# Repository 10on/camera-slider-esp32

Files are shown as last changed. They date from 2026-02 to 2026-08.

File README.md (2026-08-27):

# Camera Slider (ESP32 + TMC2209 + BLE)

Надёжный контроллер моторизованного слайдера на ESP32 с реальным‑временем генерацией шагов, калибровкой, UI на OLED, энкодером, BLE‑управлением и безопасной парковкой по данным ADXL345.

## Возможности
- Реальный таймер ESP32 генерирует STEP (ровные шаги, без влияния UI/BLE)
- Режимы: ручное движение, движение к позиции, хоминг, парковка, сон, ошибка
- Хоминг с определением полного хода и центра, сохранение в NVS
- Три режима реакции на концевики: STOP, BOUNCE, PARK
- BLE‑сервис: команды, установка скорости/позиции/тока, статус (notify)
- OLED 128x64: главный экран, меню, редакторы значений, индикация ошибок
- Энкодер: навигация по меню, быстрые правки параметров
- ADXL345: детект самопроизвольного движения и безопасная парковка
- Режим сна: выключение экрана и драйвера, пробуждение по энкодеру/BLE/движению

## Аппаратная схема (кратко)
- МК: ESP32
- Драйвер: TMC2209 (UART), R_SENSE 0.11Ω, микрошаги по умолчанию 1/32, StealthChop
- I2C (SDA=8, SCL=9): PCF8574 (0x20/0x21), SSD1306 OLED (0x3C), ADXL345 (0x53/0x1D)
- Концевики и энкодер — через PCF8574; есть fallback на GPIO
- Светодиод от PCF8574, паттерны зависят от состояния

Точное назначение пинов и адреса — см. `docs/01_hardware.md`.

## Директории и файлы
- `slider.ino` — точка входа, глобальное состояние, главный цикл
- `slider_01_config.ino` — конфиг, NVS load/save, калибровка
- `slider_02_hw.ino` — инициализация TMC2209, I2C, PCF8574, OLED, ADXL345
- `slider_03_motor.ino` — ISR таймера, STEP, линейный разгон/торможение
- `slider_04_state.ino` — машина состояний, приоритеты, обработка ошибок
- `slider_05_endstops.ino` — опрос PCF8574, концевики, энкодер
- `slider_06_homing.ino` — неблокирующий хоминг по фазам
- `slider_07_adxl.ino` — детект движения и парковка
- `slider_08_ble.ino` — BLE‑сервис, колбэки, статус notify
- `slider_09_led.ino` — индикация LED через PCF8574
- `slider_10_display.ino` — отрисовка экрана и экранов меню
- `slider_11_menu.ino` — обработка энкодера, навигация, редакторы
- `slider_12_sleep.ino` — сон/пробуждение
- `docs/` — схемы, протокол BLE, спецификации UI/системы
- `old/` — предыдущие прототипы, в т.ч. `old/main_old.ino`

## Сборка и прошивка
- Платформа: Arduino IDE (ESP32 Arduino core) или PlatformIO
- Плата: ESP32 Dev Module (или соответствующий модуль ESP32)
- Откройте `slider.ino`, убедитесь, что все `.ino` файлы в одной папке проекта
- Библиотеки:
  - TMCStepper
  - Adafruit GFX Library
  - Adafruit SSD1306
  - ESP32 BLE Arduino (BLEDevice)
  - PCF8574
  - Preferences (в составе ESP32 core)
- Подключение UART к TMC2209: используется `HardwareSerial(1)` (TX=4, RX=5), 115200 бод

## Первичный запуск
1. Соберите аппаратно согласно `docs/01_hardware.md`
2. Залейте прошивку и подайте питание
3. Выполните хоминг (меню или BLE команда `H`) — сохранится ход и центр
4. Проверьте реакции на концевики, направление, микрошаги
5. При необходимости отредактируйте параметры в меню: скорость, ток, микрошаги, режим концевиков, таймаут сна, чувствительность ADXL

## Управление с устройства (OLED + энкодер)
- Главный экран: состояние, позиция (в % при калибровке или шаги), скорость, концевики, BLE
- Кнопка энкодера — вход в меню
- Меню: Manual Move, Go to Position, Calibration, Settings
- Редакторы значений: поворот — изменение, нажать — сохранить, долгий — отмена
- Хоминг: неблокирующий, прогресс и статусы фаз на экране

Подробности UI/меню: `docs/05_ui_menu(1).md`.

## BLE протокол
- Основной API: готовые программы слайдера (`Ping-Pong` по умолчанию), их параметры и
  `START/STOP` — [формат и рекомендации для пульта](docs/11_program_api.md)
- Имя устройства: Camera_Slider
- Сервис: `4fafc201-1fb5-459e-8fcc-c5c9c331914b`
- Характеристики:
  - Command (WRITE) `beb5483e-36e1-4688-b7f5-ea07361b26a8`
    - 1 байт: `F` — вперёд, `B` — назад, `S` — стоп, `H` — хоминг, `R` — сброс ошибки
  - Speed (WRITE) `d8de624e-140f-4a22-8594-e2216b84a5f2`
    - 2 байта, uint16 LE — мкс/шаг (100..5000)
  - Position (WRITE) `a1b2c3d4-e5f6-4789-a012-3456789abcde`
    - 4 байта, int32 LE — целевая позиция в шагах (требуется калибровка)
  - Current (WRITE) `f1e2d3c4-b5a6-4978-9012-3456789abcde`
    - 2 байта, uint16 LE — ток мотора в мА (200..1500)
  - Status (READ/NOTIFY) `1c95d5e3-d8f7-413a-bf3d-7a2e5d7be87e`
    - 11 байт (v2):
      - [0..3] `currentPosition` int32 LE
      - [4] флаги: бит0 E1, бит1 E2, бит2 HOMING, бит3 CAL, бит4 GO_TO, бит5 MOVING, бит6 PARK
      - [5..8] `travelDistance` int32 LE
      - [9] `state` (enum)
      - [10] `errorCode`

`F/B`, Position, Current и legacy Speed относятся к Advanced API. Движение в сторону уже
нажатого концевика блокируется прошивкой независимо от источника команды.

Подробности Advanced API и старого формата: `docs/03_ble_protocol.md`.

## Поведение и безопасность
- Реальный‑временной контур шагов — только аппаратный таймер; UI/BLE не мешают шагам
- При потерe BLE во время движения — остановка и `STATE_ERROR`
- ADXL345: в IDLE/SLEEP детектирует самодвижение и запускает парковку к ближайшему концевику
- Режимы концевиков (глобальная настройка): STOP, BOUNCE, PARK
- Сон: по таймауту в IDLE — выключение OLED и драйвера, пробуждение по энкодеру/BLE/движению

Детали архитектуры: `docs/04_system(2).md`.

## Настройки (NVS)
Сохраняются ключевые параметры: скорость, ток, микрошаги, ramp, режим концевиков, таймаут сна, чувствительность ADXL, калибровка (ход/центр). Реализация — `slider_01_config.ino`.

## Полезные советы
- Изменение микрошагов сбрасывает калибровку — требуется новый хоминг
- Для PCF8574 используйте полноценную запись байта (`write8`), чтобы не сбрасывать pull‑up на входах
- Ток подбирайте с запасом, но без перегрева двигателя/драйвера

## FAQ / открытые вопросы
Некоторые решения зафиксированы в `docs/06_questions.md` (ramp по умолчанию, скорость хоминга, формат Status v2 и др.).

## Лицензия
Не указана. Если нужно — добавьте файл LICENSE и обновите раздел.

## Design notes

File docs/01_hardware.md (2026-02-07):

# Схема подключения

## ESP32 GPIO

| GPIO | Назначение | Направление |
|---|---|---|
| 0 | EN (TMC2209) | OUTPUT |
| 1 | STEP | OUTPUT |
| 2 | DIR | OUTPUT |
| 4 | UART TX (TMC2209)| OUTPUT |
| 5 | UART RX (TMC2209)| INPUT |
| 8 | I2C SDA | — |
| 9 | I2C SCL | — |

UART для TMC2209 — HardwareSerial(1), 115200 бод.

## I2C шина (SDA=8, SCL=9)

| Адрес | Устройство | Примечание |
|---|---|---|
| 0x20  | PCF8574 | Может быть 0x21, проверяем оба |
| 0x3C  | SSD1306 OLED | 128x64 |
| 0x53  | ADXL345 | Может быть 0x1D (если SDO=HIGH) |

## PCF8574 — распиновка

| Пин | Назначение | Режим  | Примечание |
|-----|---|---|---|
| P1  | LED | OUTPUT | Индикация |
| P2  | ENC_CLK | INPUT  | Энкодер — CLK |
| P3  | ENC_DT | INPUT  | Энкодер — DT |
| P4  | ENC_SW | INPUT  | Энкодер — кнопка |
| P5  | ENDSTOP_1  | INPUT  | Концевик 1, active LOW |
| P6  | ENDSTOP_2  | INPUT  | Концевик 2, active LOW |

P0 — не работает (физический пин вырван на плате экспандера). P7 — не используется.

Важно: PCF8574 при write() делает read-modify-write всего порта.
Если входные пины притянуты к земле, write() одного пина может сбросить pull-up на остальных.
Для записи использовать `write8()` с полным байтом, где все входы = HIGH.

## TMC2209

- R_SENSE: 0.11 Ом
- Адрес драйвера: 0b00
- Микрошаги: 32
- Режим: StealthChop (spreadCycle выключен)
- Ток по умолчанию: 800 мА (диапазон 200–1500 мА)
- toff: 4

## ADXL345

- Full resolution, +-2g (3.9 mg/LSB)
- Частота: 100 Hz
- DEVID: 0xE5 (для проверки)

Ориентация на слайдере:
- **Z** — ось движения слайдера
- **X** — вверх
- **Y** — в сторону камеры (направление съёмки)

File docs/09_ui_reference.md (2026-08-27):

# UI reference — screens, menu structure, controls

Living description of what the slider's display actually shows, kept in sync with
`firmware/src/display.cpp` (drawing) and `firmware/src/menu.cpp` (navigation). The
screenshots in `docs/ui/` are generated from the same geometry, palette, glyph bitmaps and
status-bar icons the firmware uses — they are not mockups.

> **For the designer:** every image in `docs/ui/` is a 1:1 PNG at the panel's native
> 160×128. View them scaled by an integer factor (2×/4×/8×) with nearest-neighbour
> filtering; smoothing will misrepresent how this looks on the real screen. Constraints and
> known rough edges are listed in [Notes for redesign](#notes-for-redesign).

---

## 1. The canvas

| Property | Value |
|---|---|
| Panel | ST7735, **160×128**, landscape (`setRotation(1)`) |
| Colour depth | RGB565 (16-bit) |
| Font | Adafruit GFX classic 5×7 glyph in a **6×8 cell** — no other font is loaded |
| Text sizes in use | 1 (6×8 px/char), 2 (12×16), 3 (18×24) |
| Refresh | ~10 Hz, and only when something changed |
| Composition | Full 160×128 RGB565 `GFXcanvas16` (40 KB), flushed atomically over SPI |
| Backlight | PWM, user-adjustable 10–100 % |

Because the only font is a 6 px-wide bitmap, **text width is always `chars × 6 × size`
pixels**. That gives hard limits worth designing against:

| Text size | Chars per full width (160 px) |
|---|---|
| 1 | 26 |
| 2 | 13 |
| 3 | 8 |

### Standard layout bands

Nearly every screen is built from three bands:

```
y=0    ┌──────────────────────────────┐
       │ status bar (14 px)           │  BG_PANEL + 1 px DIVIDER underneath
y=14   ├──────────────────────────────┤
       │                              │
       │ content (98 px)              │  BG_BASE
       │                              │
y=112  ├──────────────────────────────┤
       │ button hints (16 px)         │  BG_PANEL + 1 px DIVIDER on top
y=128  └──────────────────────────────┘
```

The status bar shows the terse title `SLIDER` in cyan and a battery group (right): a drawn
18×9 3-segment glyph plus a `%.1f`-formatted voltage number,
with a small amber bolt to its left when a charger is detected. List-style screens replace
the title band with the screen's own name but **keep** the battery group — every screen
shows it, including Error.

The battery glyph is drawn with primitives (`drawRect`/`fillRect`), not a bitmap: 3 segments
fill green above 66/33 %, amber below 25 %, red at 0 %. This replaced the old 5-level
`bat_0..bat_4` RGB565 bitmap set specifically to drop its "opaque black background" artifact
(see [Notes for redesign](#notes-for-redesign)).

---

## 2. Controls

Three physical inputs. **BTN1 and BTN2 sit on the left flank of the enclosure, the encoder
on the right** — which is why the hint bar groups both button hints on the left and the
encoder hint on the right, rather than spreading them left/middle/right.

| Hint bar notation | Input |
|---|---|
| `▶` / `⏸` | BTN1, short press |
| `☰` | BTN2, short press |
| `(o)` | Encoder press |

Every button hint combines the physical glyph with a terse action label (`▶ STOP`,
`☰ MENU`, and so on). `▶`/`⏸`/`☰` are hand-drawn (filled triangle, two bars, three
horizontal lines): the bitmap font has no such glyphs, so these are vector primitives, not
characters. `☰` never changes shape or meaning.
`▶`/`⏸` is the one hint icon with two states, since BTN1 doubles as the actual start/stop
toggle on Main and Ping-Pong: `▶` (play) when idle — pressing starts the move — `⏸` (pause)
while running — pressing stops it. This redraws the instant the running state flips, not
just on screen entry, so it can't go stale while sitting on the same screen.

Icon colour is normally `TEXT_SEC` (dimmed further to `TEXT_DIM` when the action is
unavailable, e.g. during homing), but a few screens tint one or both to the accent that
matches the action: Main (`▶`/`⏸` cyan, `☰` amber), Ping-Pong (`▶`/`⏸` cyan), Error (`☰` red
for "HOME").

Rotation is never shown in the hint bar — it is always "adjust the thing on screen".

General rules, unless a screen overrides them:

- **BTN1** — back one level / cancel; on Main and Ping-Pong, start/stop instead (see above).
- **BTN2** — jump to the main screen. Held for 800 ms — start homing (via a confirm dialog).
- **Encoder rotate** — change the value or move the selection; **press** — confirm/select.

One detent of the encoder equals one step. (The quadrature decoder counts four transitions
per detent and divides them down; sub-detent jitter never reaches the UI.)

---

## 3. Screen map

```
MAIN ─┬─ (o) ──────────────► GO TO POSITION ──► (back to MAIN)
      ├─ 2 ────────────────► MENU
      └─ 2 held ───────────► HOMING CONFIRM ──► CALIBRATION

MENU (full-screen carousel, one item at a time, dots show position)
 ├─ Manual Move  ─────────► MANUAL MOVE
 ├─ Position     ─────────► GO TO POSITION
 ├─ Ping Pong    ─────────► PING PONG
 ├─ Calibration  ─────────► CALIBRATION
 └─ Settings     ─────────► SETTINGS
                             ├─ Motion    ──► speed / ramp / microsteps /
                             │                endstop mode / homing speed /
                             │                pingpong start           → VALUE EDIT
                             ├─ Sleep     ──► sleep timeout / ADXL sensitivity → VALUE EDIT
                             ├─ System    ──► motor current / reset calibration /
                             │                reset error / theme / brightness /
                             │                speaker on-off            → VALUE EDIT
                             │                ├─ Diagnostics ──► DIAGNOSTICS
                             │                └─ Motor Test  ──► MOTOR TEST
                             └─ Wireless  ──► Bluetooth (On/Off)  → VALUE EDIT
                                              WiFi ──► WIFI MODE
                                                        ├─ Off
                                                        ├─ Connect ──► SCAN ──► PASSWORD ──► CONNECTING
                                                        └─ Hotspot ──► PASSWORD

ERROR      — entered automatically from any screen when a fault occurs
SLEEP      — backlight off entirely; nothing is drawn
OTA UPDATE — takes over the screen while firmware is being flashed over WiFi
```

---

## 4. Screens

### 4.1 Main

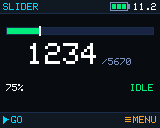
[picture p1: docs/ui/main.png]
main


The default screen. Big number is the current position in steps; the bar above it shows
where the carriage is between the two endstops (`E1` … `E2`), animated with easing.

| Input | Action |
|---|---|
| Rotate | Speed 1–100 % |
| Press | Open Go to Position |
| BTN1 (`▶`/`⏸`, cyan) | Start / stop movement in the last direction |
| BTN2 (`☰`, amber) | Open the menu |
| BTN2 held | Start homing (via confirm) |

States shown in the status line, each with its own colour: `IDLE` (green), `MOVING` /
`GO TO` (cyan), `HOMING` / `PARKING` (amber), `ERROR` (red), `SLEEP` (dim), `PING PONG`
(cyan).

| Moving | Not calibrated |
|---|---|
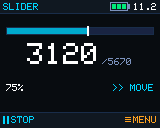
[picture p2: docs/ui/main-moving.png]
main moving
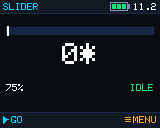
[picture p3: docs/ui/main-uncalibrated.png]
main uncalibrated
|  |  |

While moving, a direction marker (`>>` / `<<`) appears and the position bar turns cyan.
Until the slider has been homed, the position is suffixed with `*` and the bar stays empty
— travel is unknown, so there is nothing to show a fraction of.

### 4.2 Menu

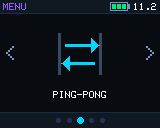
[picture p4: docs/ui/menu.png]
menu


Full-screen carousel, one item at a time: a hand-drawn vector icon (up to 60×60 px, primitives only
— no such bitmap font glyphs exist) centred in the content area, the item's name below it,
`<`/`>` chevrons at the content edges (dimmed at the first/last item — navigation itself
still wraps around, the dim chevron is just a "you're at an end" cue), and pagination dots
in the footer showing position among 5 items.

Items, in order: **Manual Move**, **Position**, **Ping Pong** (cyan icon), **Calibration**
(amber icon), **Settings** (purple icon).

| Input | Action |
|---|---|
| Rotate | Move between items |
| Press | Open the item |
| BTN1 / BTN2 | Back to main |

### 4.3 Ping Pong

No screenshot yet. Bounces the carriage between the two endstops forever, starting from a
configurable reference point (Settings → Motion → PingPong Start: Center / Endstop 1 /
Endstop 2) — this is a plain reskin of the existing bounce behavior, **not** the bounded-run
(A/B markers inside travel, dwell pause at each end, lap counter) concept sketched in the
2026-08 design handoff; that needs its own bounds-setting screen, which the handoff itself
left undesigned, and was explicitly deferred.

| Input | Action |
|---|---|
| Rotate | Speed, live |
| BTN1 (`▶`/`⏸`, cyan) | Start (heads to the reference point, then bounces) / stop |
| BTN2 | Back to the menu |

The screen uses the turn-5 hierarchy: full-width travel bar, large live position, direction
or approach state at right, and a compact speed/start/run row. Because the implemented mode
still uses the physical endstops as its bounds, its green markers sit at the two ends rather
than pretending that configurable A/B bounds exist.

### 4.4 Manual Move

| Stopped | Running |
|---|---|
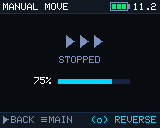
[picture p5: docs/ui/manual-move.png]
manual move
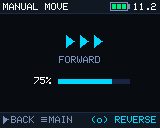
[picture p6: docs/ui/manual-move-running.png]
manual move running
|  |  |

| Input | Action |
|---|---|
| Rotate | Speed, live |
| Press | Reverse direction (reverses on the fly if already moving) |
| BTN1 | Back to the menu |
| BTN2 | Main screen |

### 4.5 Go to Position

| Calibrated | Not calibrated |
|---|---|
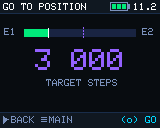
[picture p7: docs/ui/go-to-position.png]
go to position
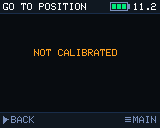
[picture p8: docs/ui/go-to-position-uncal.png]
go to position uncalibrated
|  |  |

| Input | Action |
|---|---|
| Rotate | Target position, ~1 % of total travel per detent |
| Press | Start moving to the target |
| BTN1 | Back to wherever this was opened from |
| BTN2 | Main screen |

Without calibration the slider has no coordinate system, so the screen offers nothing but
a warning.

### 4.6 Calibration / homing

| Idle | Homing in progress |
|---|---|
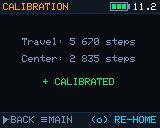
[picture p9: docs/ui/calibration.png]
calibration
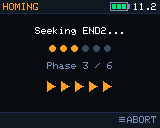
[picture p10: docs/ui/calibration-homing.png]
calibration homing
|  |  |

Homing runs in six phases (seek END1 → back off → seek END2 → back off → centre → done),
shown as a phase name and an amber progress bar. During homing every control is locked
except **BTN2 held = abort**; the measured travel and centre are stored afterwards.

### 4.7 Settings

| Settings | Motion | Sleep |
|---|---|---|
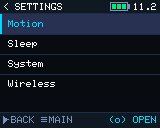
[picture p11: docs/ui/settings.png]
settings
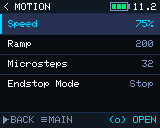
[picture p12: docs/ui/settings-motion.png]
motion
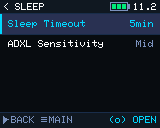
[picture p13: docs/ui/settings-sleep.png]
sleep
|  |  |  |

| System | Wireless |
|---|---|
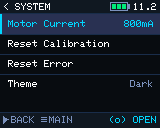
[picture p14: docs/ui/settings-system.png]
system
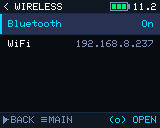
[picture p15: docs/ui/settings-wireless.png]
wireless
|  |  |

All settings screens share one list widget: 20 px rows, label left, current value right.
The selected row is a full-row highlight with a border in the selection colour and a
leading `>` marker before the label (label/value text itself stays plain white/gray, not
tinted — this replaced an earlier style that coloured the selected row's text and marked it
with a 1 px accent bar on the left edge instead). **Five rows fit at a time**; longer lists
scroll (System has eight entries as of the Speaker setting).

### 4.8 Value editor

| Numeric | Named options |
|---|---|
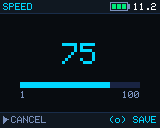
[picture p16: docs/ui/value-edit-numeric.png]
value edit numeric
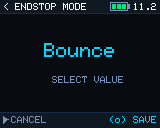
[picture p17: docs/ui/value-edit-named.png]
value edit named
|  |  |

Numeric values are centred at text size 3, with a short unit suffix (`mA`, `%`, `us`, `min`)
in `TEXT_SEC` at size 1 right after the number where the setting has an obvious one (Speed,
Homing Speed, Sleep Timeout, Motor Current, Brightness — Ramp Steps and Microsteps are
unitless). Below that, bare min/max numbers flank a progress bar directly (no "MIN"/"MAX"
caption words — one compact row instead of two). Named values (endstop mode, theme, ADXL
sensitivity, PingPong Start, Bluetooth/Speaker on-off) use size 2 and no bar — the longest
name in use, `High Contrast`, is 13 characters and only fits at that size.

| Input | Action |
|---|---|
| Rotate | Change value (microsteps step ×2 / ÷2) |
| Press | Save |
| BTN1 | Cancel |
| BTN2 | *Suppressed* — prevents discarding an edit by reflex |

### 4.9 Wireless

| WiFi mode | Scanning | Results |
|---|---|---|
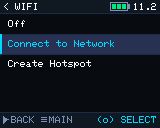
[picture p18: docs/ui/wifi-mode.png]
wifi mode
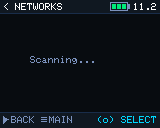
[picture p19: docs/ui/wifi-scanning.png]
scanning
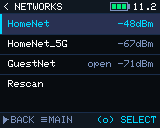
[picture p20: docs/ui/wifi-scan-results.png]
scan results
|  |  |  |

Open networks are labelled `open` next to their signal strength. The last row is always
`Rescan`.

**Password entry** — the encoder is the only text input, so characters are picked from a
74-character wheel:

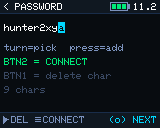
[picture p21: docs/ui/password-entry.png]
password entry


The cyan block is the cursor showing the pending character. Existing saved passwords are
pre-filled, so the common case is simply pressing BTN2.

| Input | Action |
|---|---|
| Rotate | Cycle the pending character |
| Press | Commit it and advance |
| BTN1 | Delete a character (cancels the screen when empty) |
| BTN2 | Submit (blocked for 1–7 characters: WPA2 needs at least 8) |

| Connecting | Failed |
|---|---|
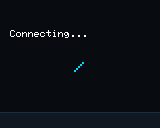
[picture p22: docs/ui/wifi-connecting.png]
connecting
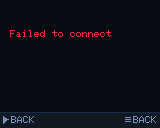
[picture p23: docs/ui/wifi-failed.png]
failed
|  |  |

Connection attempts time out after 15 s.

### 4.10 Dialogs and system screens

| Homing confirm | Error |
|---|---|
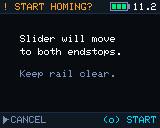
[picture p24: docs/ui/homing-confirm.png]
homing confirm
|  | error |

Homing Confirm is the one screen that asks a real yes/no question, so its footer is two
bordered "chip" buttons (`CANCEL` / `START`, amber border on the latter) instead of the
usual icon+hint row every other screen uses.

The error screen is entered automatically from any screen and its background pulses between
the base colour and dark red at 2.5 Hz. Errors: BLE connection lost, homing failed,
unexpected endstop. Footer: `▶ RESET` (dim) / `☰ HOME` (red).

**OTA update** — shown while firmware is flashed over WiFi. The main loop is fully blocked
during the transfer, so this screen is painted directly from the update callbacks:

ota update

### 4.11 Service screens

Reached from Settings → System. Both suppress all normal navigation, so nothing can be
triggered by accident while probing hardware; **hold BTN1+BTN2 for 3 s to leave**.

| Diagnostics | Motor test |
|---|---|
| diagnostics | motor test |

**Diagnostics** reads the GPIO pins directly, bypassing debouncing and the menu entirely,
so a dead switch can be told apart from a software fault. Both status LEDs mirror the
endstops here so they can be verified too.

**Motor test** jogs the motor on the bench: BTN1/BTN2 tap to run backward/forward, tapping
again (or the encoder press) stops, rotation sets speed live. Endstops are still respected.

---

## 5. Themes

Selectable in Settings → System → Theme, applied instantly and remembered.

| | Dark (default) | Light | High Contrast |
|---|---|---|---|
| Main | dark | light | hc |
| Menu | dark | light | hc |
| System | dark | light | hc |

### Palette

Colours are RGB565. Note the display cannot show more than 5/6/5 bits per channel, so
fine gradients between near neighbours will band.

| Role | Dark | Light | High Contrast |
|---|---|---|---|
| `BG_BASE` — page background | `#0A0C14` | `#F4F6FA` | `#000000` |
| `BG_PANEL` — status/hint bars | `#111827` | `#E7ECF5` | `#000000` |
| `BG_CARD` — tiles, bar troughs | `#1C2540` | `#FFFFFF` | `#000000` |
| `BG_HIGHLIGHT` — selected row/tile | `#283255` | `#D6E4FF` | `#FFFFFF` |
| `COL_SEL` — selected text/border | `#00D4FF` | `#0088B3` | `#000000` |
| `COL_CYAN` — motion / active | `#00D4FF` | `#0088B3` | `#00FFFF` |
| `COL_GREEN` — idle / success | `#00E87A` | `#128A4A` | `#00FF00` |
| `COL_AMBER` — homing / warning | `#FFA020` | `#B36B00` | `#FFEA00` |
| `COL_RED` — error / endstop hit | `#FF2840` | `#C81E3A` | `#FF0000` |
| `TEXT_PRI` — primary text | `#FFFFFF` | `#12141C` | `#FFFFFF` |
| `TEXT_SEC` — secondary text | `#7A90BB` | `#4A5670` | `#E6E6E6` |
| `TEXT_DIM` — hints, disabled | `#3A4A66` | `#8B96AC` | `#AAAAAA` |
| `DIVIDER` — 1 px rules | `#1E2E48` | `#D0D8E4` | `#666666` |

High Contrast deliberately **inverts the selection** (white block, black text) instead of
tinting it, because every accent there is already a saturated colour on black.

A 2026-08 external UI redesign handoff (mockups at real 160×128, turns 3-5) specified this
exact Dark palette independently, hex-for-hex — confirmed by converting every value back to
RGB565 and comparing. So the redesign changed screen layouts, icons, and content density,
not colour.

---

## 6. Notes for redesign

Things worth knowing before proposing changes — constraints first, then existing weak spots.

**Hard constraints**

1. **One bitmap font, three sizes.** There is no proportional font and no font scaling
   beyond integer multiples. Any type hierarchy must come from sizes 1/2/3, colour and
   spacing. Adding a font costs flash, and the build is at ~86 % of its partition.
2. **No transparency, no antialiasing.** Everything is hard-edged; overlapping elements
   must be composed by drawing order.
3. **The frame buffer is finite.** A full RGB565 `GFXcanvas16` consumes 40 KB of heap. All
   widgets compose into it, then `flushFrame()` transfers the finished frame in one SPI
   transaction, so intermediate clears are never visible. A second full buffer would be an
   unjustified extra 40 KB on this non-PSRAM ESP32.
4. **Icons should stay as primitives, not bitmaps or text glyphs.** Photographic/AI-rendered
   icons were illegible at 32 px and cannot follow the theme; the bitmap font also has none
   of the glyphs (`▶ ⏸ ☰ ‹ › ✓`) a design mockup might specify as literal Unicode text. The
   current UI hand-draws all of it with `drawLine`/`drawRect`/`drawCircle`/`fillTriangle` —
   button hints, the 5 menu carousel icons, page dots, chevrons.

**Deviations from the 2026-08 redesign handoff**
- **Ping-Pong stayed the existing simple bounce** (reskinned to the new visual language, see
  §4.3) instead of the handoff's bounded-run concept (settable A/B markers, dwell pause,
  lap counter) — a real new feature, and the handoff's own README admits the screen for
  setting A/B was never designed. Deferred by explicit decision, not an oversight.
- **Per-icon hint colour is applied only where the handoff was unambiguous** (Main, Error,
  Ping-Pong — see §2), not hex-matched screen-by-screen; the handoff's own colour choices
  there read as bespoke per screen rather than a strict system (e.g. BTN2 is amber on Main
  but plain gray on Ping-Pong for the same "go back" action).
- **"10 px" text was approximated at size 1 (6×8).** The bitmap font only scales in integer
  multiples of 6×8 — there is no size between 1 (8 px-ish) and 2 (16 px) to match what the
  mockup's CSS called "10px" for menu titles/secondary values.

**Known weak spots**

- **High Contrast flattens low-priority fills.** `BG_CARD` and `BG_BASE` are both pure black
  there, so hierarchy depends more heavily on outlines and the selected carousel icon.
- **The hint bar is still width-constrained.** The 16 px band gives the glyphs enough
  height, but the right-aligned encoder action text can still collide with a long menu
  title on the busiest screens.
- **Mixed information density.** The service screens are deliberately dense text dumps,
  while the main screen is very sparse. They were designed at different times and do not
  share a visual system.
- **No transition animation.** Screens swap instantly. Only the position bar eases, and the
  spinner/error pulse animate.

**Regenerating the screenshots**

```bash
python3 tools/ui_preview/extract_assets.py       # only if the font or icons changed
node tools/ui_preview/render_node.js              # regenerate every 1:1 docs/ui PNG
```

`tools/ui_preview/index.html` re-implements the Adafruit GFX primitives the firmware draws
with, so it must be updated alongside `display.cpp` for these images to stay truthful.

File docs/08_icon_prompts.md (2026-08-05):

# Icon Generation Prompts — Camera Slider UI

Документ содержит промпты для AI-генерации иконок. Структура:
- **System block** — вставляется в начало каждого промпта (стиль, палитра, ограничения)
- **Per-size templates** — шаблон для каждого из трёх размеров
- **Icon catalog** — готовые промпты для каждой иконки

Рекомендуемые инструменты: **Midjourney** (флаг `--style raw --ar 1:1`), **DALL-E 3**, **Stable Diffusion** с pixel-art LoRA, или любой инструмент с поддержкой pixel art стиля. Для финальной доводки до точных пикселей — **Aseprite**.

---

## System Block (вставлять в начало каждого промпта)

```
Pixel art icon for embedded 160x128 color LCD display (ST7735).
Style: clean technical pixel art, sharp edges, no anti-aliasing, no gradients, no glow effects.
Background: transparent (checkerboard).
Limited palette: exactly 2-3 colors from the provided list + transparent.
Rendered as flat opaque pixels only.
No shadow, no outline stroke unless it IS one of the colors.
Suitable for direct use as a bitmap sprite on a microcontroller display.
```

---

## Цветовая палитра (ссылочные значения для промптов)

```
CYAN     #00D4FF  — движение, активное, прогресс
GREEN    #00E87A  — OK, idle, готово
AMBER    #FFA020  — предупреждение, разгон
RED      #FF2840  — ошибка, стоп, эндстоп
PURPLE   #9060FF  — настройки
WHITE    #FFFFFF  — основной элемент, деталь
TEXT_SEC #7A90BB  — корпус, неактивные части
BG_CARD  #1C2540  — если нужен темный фон плитки
```

---

## Серия A — 32×32, главное меню (2–3 цвета)

### Шаблон

```
[SYSTEM BLOCK]
Canvas: 32x32 pixels.
Colors: [COLOR_1] for body/silhouette, [COLOR_2] for accent/highlight, [optional COLOR_3] for detail.
Subject: [ICON DESCRIPTION]
The icon should be centered, filling roughly 24x24 pixels of the 32x32 canvas (4px padding).
No text, no letters, no numbers inside the icon.
```

### Промпты серии A

**ic32_speed — спидометр**
```
[SYSTEM BLOCK]
Canvas: 32x32 pixels.
Colors: #7A90BB for gauge body and tick marks, #00D4FF for the needle/pointer, #FFFFFF for the center dot.
Subject: speedometer gauge icon. Semicircular dial with evenly spaced tick marks along the arc. A sharp triangular needle pointing to the upper-right (high speed position). Small circle at needle pivot. Minimalist, technical, no labels.
The icon should be centered, filling roughly 26x26 pixels of the 32x32 canvas.
```

**ic32_current — ток мотора**
```
[SYSTEM BLOCK]
Canvas: 32x32 pixels.
Colors: #FFA020 for the outer circle, #FFFFFF for the lightning bolt shape.
Subject: electric current icon. Filled circle with a clean lightning bolt (zigzag arrow, top to bottom) cut out or drawn inside it. The bolt should be thick enough to read at small size — 3px minimum stroke.
The icon should be centered, filling roughly 24x24 pixels of the 32x32 canvas.
```

**ic32_microstep — деление шага**
```
[SYSTEM BLOCK]
Canvas: 32x32 pixels.
Colors: #7A90BB for bracket lines and grid dots, #00D4FF for the highlighted center dot.
Subject: microstep grid icon. Two square brackets [ ] on left and right sides. Inside: a 3x3 or 4x4 regular grid of small square dots. The center dot is a different color (accent). Represents fine subdivision/resolution.
The icon should be centered, filling roughly 24x24 pixels of the 32x32 canvas.
```

**ic32_ramp — разгон/торможение**
```
[SYSTEM BLOCK]
Canvas: 32x32 pixels.
Colors: #00D4FF for the ramp/trapezoid shape, #7A90BB for baseline and optional axis lines.
Subject: acceleration ramp icon. A trapezoid shape viewed from the front — flat top, slanted left side (ramp up), vertical right side, flat bottom baseline. Represents motor acceleration profile. Clean geometric shape.
The icon should be centered, filling roughly 26x20 pixels of the 32x32 canvas, vertically centered.
```

**ic32_home — хоминг**
```
[SYSTEM BLOCK]
Canvas: 32x32 pixels.
Colors: #00E87A for the roof triangle, #FFFFFF for walls and door opening.
Subject: simple house/home icon. Equilateral triangle roof on top, square body below, small centered rectangular door cutout at the bottom of the body. Classic minimal house silhouette. No windows.
The icon should be centered, filling roughly 24x26 pixels of the 32x32 canvas.
```

**ic32_sleep — таймаут сна**
```
[SYSTEM BLOCK]
Canvas: 32x32 pixels.
Colors: #9060FF for the crescent moon, #FFFFFF for three small star dots.
Subject: sleep/night icon. A crescent moon (right-facing, thick, smooth arc shape in pixel art). Three small 2x2 pixel star dots scattered in the upper-right area around the moon. Minimal, clear silhouette.
The icon should be centered, filling roughly 24x24 pixels of the 32x32 canvas.
```

**ic32_endstop — режим эндстопов**
```
[SYSTEM BLOCK]
Canvas: 32x32 pixels.
Colors: #7A90BB for the horizontal rail/track, #FF2840 for the two end stops/bumpers.
Subject: rail with end stops icon. A horizontal line (rail/track) spanning the full width of the icon. At each end, a thick vertical bar (end stop) — like the letter H rotated 90 degrees, or railroad bumpers. Arrow heads pointing inward from both stops toward center (optional, if readable at this size).
The icon should be centered vertically, filling roughly 28x12 pixels centered in the 32x32 canvas.
```

**ic32_adxl — акселерометр / детектор наклона**
```
[SYSTEM BLOCK]
Canvas: 32x32 pixels.
Colors: #7A90BB for the cube body faces, #00D4FF for the three axis lines (X, Y, Z arrows).
Subject: 3D accelerometer icon. A small isometric cube in the lower-left area of the icon. Three axis arrows (X rightward, Y upward, Z toward viewer at isometric angle) extending from the cube's corner. Each arrow is a line with a small arrowhead. Represents 3-axis measurement.
The icon should be centered, filling roughly 26x26 pixels of the 32x32 canvas.
```

**ic32_settings — системные настройки**
```
[SYSTEM BLOCK]
Canvas: 32x32 pixels.
Colors: #7A90BB for the gear body/teeth, #FFFFFF for the center circle cutout.
Subject: settings gear/cog icon. A single gear with 6-8 evenly spaced rectangular teeth around the perimeter. A circle cutout in the center. Symmetrical, clean, classic settings icon. Teeth should be distinct and readable at 32px.
The icon should be centered, filling roughly 26x26 pixels of the 32x32 canvas.
```

**ic32_ble — Bluetooth / соединение**
```
[SYSTEM BLOCK]
Canvas: 32x32 pixels.
Colors: #00D4FF for all elements.
Subject: Bluetooth symbol icon. Classic Bluetooth logo: vertical line with two diagonal lines forming a shape like a stylized 'B' — upper-right diagonal and lower-right diagonal crossing the vertical. The symbol should be thick enough (2-3px strokes) to read at small size.
The icon should be centered, filling roughly 14x24 pixels of the 32x32 canvas.
```

**ic32_calib — калибровка / измерение**
```
[SYSTEM BLOCK]
Canvas: 32x32 pixels.
Colors: #7A90BB for the ruler body, #FFA020 for the position marker/arrow.
Subject: calibration ruler icon. A horizontal ruler bar with 5-7 evenly spaced tick marks of alternating heights (major and minor ticks). Below the ruler, a downward-pointing triangle marker (like a position caret) positioned at roughly 2/3 along the ruler. Represents measured travel distance.
The icon should be centered, filling roughly 28x16 pixels of the 32x32 canvas, vertically centered.
```

**ic32_goto — переход к позиции**
```
[SYSTEM BLOCK]
Canvas: 32x32 pixels.
Colors: #00D4FF for the arrow and dashed path, #FFFFFF for the destination flag/marker.
Subject: go-to position icon. A dashed horizontal line (path) going left to right. At the right end, a small flag or vertical marker (like a finish line post). An arrow head pointing right at the end of the path. Represents moving to a target position.
The icon should be centered, filling roughly 28x14 pixels of the 32x32 canvas, vertically centered.
```

**ic32_display — настройки экрана**
```
[SYSTEM BLOCK]
Canvas: 32x32 pixels.
Colors: #7A90BB for the monitor/screen frame, #FFA020 for the brightness symbol.
Subject: display settings icon. A small rounded rectangle (monitor/screen frame) taking up left 2/3 of icon. Inside the screen: a simplified sun symbol (small circle with 4 short rays at cardinal directions) representing brightness. Clean, readable.
The icon should be centered, filling roughly 26x22 pixels of the 32x32 canvas.
```

---

## Серия B — 16×16, подменю (2 цвета)

### Шаблон

```
[SYSTEM BLOCK]
Canvas: 16x16 pixels.
Colors: [COLOR_1] for main shape, [COLOR_2] for accent (if needed). Maximum 2 colors + transparent.
Subject: [SIMPLIFIED VERSION OF 32x32 ICON — remove small details, keep silhouette only]
Pixel art, very simplified, readable silhouette. At 16px: keep only the essential shape, drop all fine details (no tick marks, no minor elements). The silhouette alone must be immediately recognizable.
The icon should fill roughly 12x12 pixels centered in the 16x16 canvas.
```

**Промпты серии B** — для каждой иконки добавить в шаблон:

| Иконка | Subject для 16×16 | Цвет 1 | Цвет 2 |
|---|---|---|---|
| `ic16_speed` | Semicircular dial arc with a single needle, no ticks | #7A90BB | #00D4FF |
| `ic16_current` | Circle with lightning bolt inside | #FFA020 | #FFFFFF |
| `ic16_microstep` | 3x3 grid of dots, center dot different | #7A90BB | #00D4FF |
| `ic16_ramp` | Trapezoid shape, flat top, slanted left side | #00D4FF | — |
| `ic16_home` | Triangle roof + square body + door, minimal | #00E87A | #FFFFFF |
| `ic16_sleep` | Crescent moon only, no stars | #9060FF | — |
| `ic16_endstop` | Short horizontal line with thick bars at each end | #7A90BB | #FF2840 |
| `ic16_adxl` | Three axis arrows from a point, no cube | #7A90BB | #00D4FF |
| `ic16_settings` | 6-tooth gear with center hole | #7A90BB | — |
| `ic16_ble` | Bluetooth symbol, thick strokes | #00D4FF | — |
| `ic16_calib` | Ruler with 3 ticks + triangle marker | #7A90BB | #FFA020 |
| `ic16_goto` | Arrow pointing right with small flag at tip | #00D4FF | #FFFFFF |
| `ic16_display` | Rectangle frame with sun symbol inside | #7A90BB | #FFA020 |
| `ic16_high_contrast` | Half-black half-white circle (yin-yang style, simplified) | #FFFFFF | — |

---

## Серия C — 12×12, статусбар (1–2 цвета)

### Шаблон

```
[SYSTEM BLOCK]
Canvas: 12x12 pixels.
Colors: [COLOR] only + transparent. Absolute maximum 2 colors.
Subject: [ICON DESCRIPTION — extreme silhouette only]
At 12px everything is a silhouette. 1-2px strokes maximum. The entire icon must be readable in a 12x12 box at arm's length on a small screen. Reduce to pure geometric primitive.
```

**Промпты серии C:**

| Иконка | Subject | Цвет |
|---|---|---|
| `ic12_bt_on` | Bluetooth symbol, 2px stroke | #00D4FF |
| `ic12_bt_off` | Bluetooth symbol with diagonal strike-through line | #3A4A66 |
| `ic12_bat_0` | Battery outline (rectangle + small nub), empty inside | #FF2840 |
| `ic12_bat_1` | Battery outline with 1 filled segment on left | #FFA020 |
| `ic12_bat_2` | Battery outline with 2 filled segments | #FFA020 |
| `ic12_bat_3` | Battery outline with 3 filled segments | #00E87A |
| `ic12_bat_4` | Battery outline fully filled | #00E87A |
| `ic12_hc_on` | Small "HC" text replaced by: a square half-filled diagonally (contrast symbol) | #FFFFFF |

---

## Серия D — 10×10, кнопки-подсказки (монохром)

Для этой серии AI-генерация избыточна — проще нарисовать вручную в Aseprite или использовать встроенные глифы шрифта. Если всё же нужен промпт:

```
[SYSTEM BLOCK]
Canvas: 10x10 pixels.
Colors: #FFFFFF only + transparent. Pure monochrome.
Subject: [ICON] as a minimal 1-bit icon. Maximum 2px stroke width. Must be readable at 10x10.
```

| Иконка | Subject |
|---|---|
| `ic10_fwd` | Right-pointing filled triangle (play button) |
| `ic10_bwd` | Left-pointing filled triangle |
| `ic10_stop` | Filled square |
| `ic10_ok` | Checkmark, L-shape rotated, 2px stroke |
| `ic10_cancel` | X cross, 2px stroke, diagonal lines |
| `ic10_back` | Left arrow with tail curving up (return arrow) |
| `ic10_menu` | Three horizontal lines, equal spacing |
| `ic10_home` | Triangle on top of square, minimal |
| `ic10_reset` | Circular arrow (arc with arrowhead, open circle) |
| `ic10_error` | Exclamation mark centered |

---

## Добавление новой иконки — чеклист

1. Определить серию (A/B/C/D) по контексту использования
2. Скопировать шаблон нужной серии
3. Заполнить поля:
   - `Canvas` — из шаблона (не менять)
   - `Colors` — выбрать из палитры выше, не более 3 цветов для A, 2 для B/C
   - `Subject` — описать форму, начиная с самого крупного элемента к мелкому
4. Добавить строку в таблицу иконок в `docs/07_ui_kit.md`
5. Сгенерировать, при необходимости довести в Aseprite до точной сетки

---

## Советы по доводке в Aseprite

После генерации AI-изображения:

1. Открыть в Aseprite, масштаб 800%
2. `Sprite → Color Mode → Indexed` → задать палитру из 2–3 нужных цветов
3. `Edit → Replace Color` — убрать все оттенки, которых нет в палитре
4. Вручную почистить пиксели на границах (избавиться от антиалиасинга)
5. Экспортировать как PNG с прозрачностью
6. Конвертировать в C-массив PROGMEM через утилиту (см. следующий раздел)

### Конвертация PNG → C-массив

Для LovyanGFX/TFT_eSPI иконки хранятся как `const uint8_t icon_name[] PROGMEM`.

Инструменты:
- **image2cpp** (онлайн, javl.github.io/image2cpp) — для 1-bit и RGB565
- **LVGL Image Converter** (онлайн) — для indexed и RGB565
- Кастомный Python-скрипт (см. ниже)

```python
# tools/png_to_progmem.py — базовый скрипт конвертации
# Использование: python png_to_progmem.py icon_speed_32.png ic32_speed
from PIL import Image
import sys

def convert(filename, varname):
    img = Image.open(filename).convert('RGBA')
    w, h = img.size
    pixels = list(img.getdata())

    print(f"// {w}x{h} px")
    print(f"const uint16_t {varname}[{w*h}] PROGMEM = {{")
    row = []
    for r, g, b, a in pixels:
        if a < 128:
            rgb = 0x0000  # transparent → black (use colorkey)
        else:
            rgb = ((r & 0xF8) << 8) | ((g & 0xFC) << 3) | (b >> 3)
        row.append(f"0x{rgb:04X}")
        if len(row) == w:
            print("  " + ", ".join(row) + ",")
            row = []
    print("};")

if __name__ == "__main__":
    convert(sys.argv[1], sys.argv[2])
```

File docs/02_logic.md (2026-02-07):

# Логика работы (old/main_old.ino)

## Общая архитектура

ESP32 работает как BLE-периферия с именем "Camera_Slider". Управление через BLE-характеристики с callback-ами. Статус отдаётся по notify каждые 100мс.

При старте загружается калибровка из NVS. Если есть — слайдер знает свой рабочий ход и центр.

## Состояния

Четыре булевых флага определяют поведение в loop():

| Флаг | Что делает |
|---|---|
| isMoving | Непрерывное движение вперёд/назад (ручной режим) |
| isHoming | Процедура калибровки (блокирующая) |
| isMovingToPosition| Движение к целевой позиции (пошагово в loop) |
| isCalibrated | Можно ли использовать позиционирование |

Приоритет в loop(): homing > moveToPosition > ручное движение.

## Ручное движение (F/B/S)

- Команда F — DIR_PIN LOW, isMoving=true, каретка едет вперёд
- Команда B — DIR_PIN HIGH, isMoving=true, каретка едет назад
- Команда S — всё стоп (сбрасывает все три флага движения)

При каждом шаге обновляется currentPosition (+1 при DIR LOW, -1 при DIR HIGH).

При достижении концевика — reverseDirection(): смена направления + откат на 200 шагов. Движение продолжается.

## Процедура хоминга (H)

Блокирующая процедура в doHoming(), вызывается из loop():

1. Едем назад (DIR HIGH) до ENDSTOP_1
   - Если по пути встретили ENDSTOP_2 — ошибка, выход
2. Откат на 200 шагов вперёд, currentPosition = 0
3. Едем вперёд (DIR LOW) до ENDSTOP_2, считаем шаги
4. travelDistance = кол-во шагов, откат на 200 шагов назад
5. Вычисляем центр: centerPosition = travelDistance / 2
6. Едем к центру
7. Сохраняем в NVS: travelDistance, centerPosition, calibrated=true

Скорость хоминга: 300 мкс/шаг (быстрее стандартных 800).

## Движение к позиции

При записи в Position-характеристику:
- Позиция ограничивается диапазоном [0, travelDistance]
- Требуется калибровка (isCalibrated)
- moveToPosition() вызывается из loop(), один шаг за итерацию
- Остановка когда |stepsToGo| < 5

## Хранение (NVS)

Namespace: "stepper"

| Ключ | Тип  | Описание |
|---|---|---|
| travel | Long | Полный ход в шагах |
| center | Long | Центральная позиция в шагах |
| calibrated | Bool | Есть ли калибровка |

Загрузка при старте (loadCalibration), сохранение после хоминга (saveCalibration).

## Скорость

Задаётся через BLE, 2 байта little-endian, в микросекундах между шагами.
Диапазон: 100–5000 мкс/шаг.
По умолчанию: 800 мкс/шаг.

## Ток мотора

Задаётся через BLE, 2 байта little-endian, в мА.
Диапазон: 200–1500 мА.
По умолчанию: 800 мА.
Применяется сразу: driver.rms_current(motorCurrent).

## Отключение BLE

При разрыве соединения — все движения останавливаются (isMoving, isHoming, isMovingToPosition = false).

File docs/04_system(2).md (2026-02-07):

# Camera Slider — System Specification (v1.1)

## 1. Назначение документа

Документ описывает системную архитектуру слайдера:
- управление мотором в real-time
- машину состояний
- работу ADXL345
- режимы сна и парковки
- обработку ошибок
- расширяемую конфигурацию, доступную через BLE и UI

Документ является основной спецификацией для прошивки.

---

## 2. Архитектура управления мотором

### 2.1. Real-time контур движения

- Генерация STEP осуществляется ТОЛЬКО аппаратным таймером ESP32
- Таймер является единственным источником шагов
- STEP/DIR не управляются из loop(), BLE или UI
- Все внешние события влияют на движение через атомарные флаги

Это гарантирует:
- равномерные шаги
- отсутствие рассинхрона
- независимость от BLE, OLED и I2C

---

### 2.2. Ускорение и замедление (Ramp)

Используется короткий линейный ramp:
- длительность: десятки миллисекунд
- применяется при старте и остановке
- не влияет на позиционирование

Ramp реализуется внутри логики таймера.

---

## 3. Машина состояний

### 3.1. Состояния

IDLE — мотор выключен  
MANUAL_MOVING — ручное движение  
MOVING_TO_POS — движение к позиции  
HOMING — калибровка  
PARKING — аварийная парковка  
ERROR — ошибка  
SLEEP — логический сон  

---

### 3.2. Приоритет

ERROR  
HOMING  
PARKING  
MOVING_TO_POS  
MANUAL_MOVING  
IDLE / SLEEP  

---

## 4. ADXL345 — безопасность

### 4.1. Назначение

ADXL345 используется исключительно для безопасности:
- детект самопроизвольного движения
- определение направления движения
- инициирование PARKING

Не используется для позиционирования или стабилизации.

---

### 4.2. Аварийная парковка

Условия:
- состояние IDLE или SLEEP
- мотор выключен
- нет активных команд

При детекте движения:
1. определяется направление
2. состояние → PARKING
3. движение к соответствующему концевику
4. при срабатывании концевика мотор выключается
5. состояние → IDLE или SLEEP

---

## 5. Режим сна

### 5.1. Вход в сон

После N минут бездействия:
- мотор обесточен
- экран выключен
- BLE может оставаться активным
- ADXL активен

---

### 5.2. Поведение в сне

#### Вертикально / под углом
- при начале движения → PARKING
- после парковки возврат в SLEEP

#### Горизонтально
- движения нет → остаёмся в SLEEP

Пробуждение:
- энкодер
- BLE
- (опционально) ADXL

---

## 6. Концевики

- Концевики опрашиваются асинхронно (через PCF8574)
- Опрос в loop(), не в ISR
- При срабатывании выставляется флаг stopRequested
- Таймер корректно останавливает движение

Запас хода после срабатывания учитывается.

---

## 7. Конфигурационные режимы движения

### 7.1. Режим реакции на концевик (Endstop Mode)

Настраиваемая логика, применимая:
- через BLE
- через UI

Режимы:

0 — STOP  
При срабатывании концевика:
- движение останавливается
- состояние → IDLE

1 — BOUNCE  
При срабатывании:
- движение останавливается
- направление меняется
- движение продолжается (отъезд от концевика)

2 — PARK  
При срабатывании:
- движение продолжается до уверенного упора
- мотор выключается
- состояние → IDLE / SLEEP

Режим является глобальной настройкой.

---

### 7.2. Режим окончания ручного движения

Определяет, что делать после MANUAL_MOVING без команды Stop:

- Stop at Endstop
- Reverse at Endstop
- Hold Position

---

## 8. Микрошаги

- Микрошаги — глобальная настройка
- Диапазон: любые разумные значения (1…256)
- Изменение микрошагов:
  - останавливает мотор
  - сбрасывает калибровку
  - требует нового HOMING

---

## 9. BLE Disconnect

При потере BLE во время движения:
- мотор останавливается
- состояние → ERROR
- errorCode = BLE_LOST

В IDLE и SLEEP игнорируется.

---

## 10. Статус устройства

### 10.1. Status v1
Без изменений.

### 10.2. Status v2
Добавляется:
- errorCode
- state

---

## 11. LED-индикация

- BLE подключён → горит
- BLE нет → медленно мигает
- движение без BLE → выключен
- ERROR → постоянный свет или быстрый мигание

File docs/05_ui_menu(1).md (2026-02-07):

# Camera Slider — UI & Menu Specification (v1.1)

## 1. Общие принципы

- UI не управляет мотором напрямую
- UI работает через системную логику
- UI не нарушает state machine

---

## 2. Частота обновления

- Рекомендуемая частота: 10–20 Гц
- Максимум: 30 Гц
- Обновление только при изменениях

---

## 3. Главный экран

Отображает:
- позицию
- состояние
- скорость
- BLE статус
- ошибку

Энкодер:
- поворот — скорость
- нажатие — меню

---

## 4. Главное меню

Manual Move  
Go to Position  
Programs  
Calibration  
Settings  

---

## 5. Manual Move

- направление
- скорость
- START / STOP

Поведение на концевиках определяется Endstop Mode.

---

## 6. Settings

### 6.1. Motion Settings

- Speed
- Acceleration
- Microsteps
- Endstop Mode

### 6.2. Sleep Settings

- Sleep Timeout
- ADXL Sensitivity
- Wake on Motion (опционально)

### 6.3. System

- Motor Current
- Reset Calibration
- Reset Error

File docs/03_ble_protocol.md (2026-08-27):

# BLE-протокол

Основной пользовательский сценарий описан в [Program API](11_program_api.md): готовые
программы выбираются, настраиваются и запускаются на самом слайдере. Характеристики ниже
составляют Advanced/compatibility API для ручного управления и диагностики.

Имя устройства: **Camera_Slider**

## Сервис

UUID: `4fafc201-1fb5-459e-8fcc-c5c9c331914b`

## Характеристики

### Program (READ / WRITE / NOTIFY)

UUID: `c0f1c001-0000-4000-8000-00000000c0de`

Версионированное управление готовыми программами. Программа по умолчанию — Ping-Pong.
Форматы request/status, готовые пакеты и требования к пульту приведены в
[docs/11_program_api.md](11_program_api.md).

### Command (WRITE)
UUID: `beb5483e-36e1-4688-b7f5-ea07361b26a8`

1 байт — код команды:

| Байт | Команда  | Действие |
|---|---|---|
| 'F'  | Forward  | Непрерывное движение вперёд / смена направления |
| 'B'  | Backward | Непрерывное движение назад / смена направления  |
| 'S'  | Stop | Остановка любого движения |
| 'H'  | Home | Запуск калибровки (хоминг) |
| 'G'  | Go home  | Переход к сохранённой домашней позиции |
| 'Z'  | Set home | Сохранить текущую позицию как домашнюю |
| 'R'  | Reset | Сброс состояния ошибки |

`F` и `B` задают направление ручного движения и идемпотентны: повтор той же команды
ничего не меняет, противоположная команда меняет направление. Команда блокируется, если
соответствующий концевик уже нажат. Во время хоминга, движения к позиции, парковки и
Ping-Pong обе команды игнорируются.

### Speed (WRITE)
UUID: `d8de624e-140f-4a22-8594-e2216b84a5f2`

2 байта, uint16, little-endian — задержка между шагами в микросекундах.

```
[low_byte, high_byte]
```

Диапазон: 100–5000. Меньше = быстрее.

### Position (WRITE)
UUID: `a1b2c3d4-e5f6-4789-a012-3456789abcde`

4 байта, int32, little-endian — целевая позиция в шагах.

```
[byte0, byte1, byte2, byte3]
```

Ограничивается в [0, travelDistance]. Требуется калибровка. Без неё — команда игнорируется.

### Current (WRITE)
UUID: `f1e2d3c4-b5a6-4978-9012-3456789abcde`

2 байта, uint16, little-endian — ток мотора в мА.

```
[low_byte, high_byte]
```

Диапазон: 200–1500. Применяется мгновенно.

### Status (READ / NOTIFY)
UUID: `1c95d5e3-d8f7-413a-bf3d-7a2e5d7be87e`

11 байт, отправляется notify каждые 100мс при активном соединении. Первые 9 байт
совместимы со старым форматом статуса.

```
Байты 0–3: currentPosition (int32, little-endian)
Байт  4:   флаги (битовая маска)
Байты 5–8: travelDistance (int32, little-endian)
Байт  9:   state (uint8)
Байт  10:  errorCode (uint8)
```

Битовая маска (байт 4):

| Бит | Маска | Значение |
|-----|---|---|
| 0 | 0x01  | ENDSTOP_1 сработал |
| 1 | 0x02  | ENDSTOP_2 сработал |
| 2 | 0x04  | Идёт хоминг |
| 3 | 0x08  | Калибровка выполнена |
| 4 | 0x10  | Движение к позиции |
| 5 | 0x20  | Мотор движется |
| 6 | 0x40  | Идёт парковка |

`state`: `0=IDLE`, `1=MANUAL`, `2=MOVE_TO_POS`, `3=HOMING`, `4=PARKING`,
`5=ERROR`, `6=SLEEP`, `7=PING_PONG`.

`errorCode`: `0=NONE`, `1=BLE_LOST`, `2=HOMING_FAIL`,
`3=ENDSTOP_FAULT` (зарезервирован).

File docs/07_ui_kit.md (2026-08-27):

# UI Kit: Camera Slider Controller

**Платформа:** ESP32-WROOM-32 + ST7735 160×128 (1.8", RGB565, SPI)
**Библиотека:** LovyanGFX (лучше TFT_eSPI по DMA и Sprite на S3) + Sprite double-buffering
**Буфер:** один полный RGB565-кадр 160×128 (40 KB) в heap; PSRAM не требуется

---

## 1. Цветовая система

**Контекст использования:** в помещении под студийным освещением (softbox). Приоритет — красота и информативность, а не максимальный контраст. Высококонтрастный режим существует как опциональная настройка (см. раздел 1.2).

### 1.1 Основная тема (Default Dark)

### Палитра (RGB565)

```
# Фоны
BG_BASE     #0A0C14   почти черный с синим подтоном — весь экран
BG_PANEL    #111827   панели, шапки
BG_CARD     #1C2540   карточки, пункты меню
BG_HIGHLIGHT #283255  выбранный пункт меню

# Акценты — смысловые
CYAN        #00D4FF   активное движение, прогресс, OK
GREEN       #00E87A   idle / всё хорошо
AMBER       #FFA020   предупреждение, частичное состояние
RED         #FF2840   ошибка, стоп, активный эндстоп
PURPLE      #9060FF   настройки, secondary action
WHITE       #FFFFFF   primary text, крупные цифры

# Текст и вспомогательное
TEXT_PRI    #FFFFFF
TEXT_SEC    #7A90BB   подписи, единицы измерения
TEXT_DIM    #3A4A66   disabled, placeholder
DIVIDER     #1E2E48   разделители
```

### 1.2 Высококонтрастный режим (High Contrast)

Включается в меню `Display → High Contrast: ON`. Переключает только цветовые токены — все остальные компоненты и экраны остаются прежними.

```
# Переопределения токенов в HC-режиме
BG_BASE      #000000   чистый черный
BG_PANEL     #000000
BG_CARD      #0A0A0A
BG_HIGHLIGHT #003060   ярко-синий фон выбора
TEXT_PRI     #FFFFFF
TEXT_SEC     #CCCCCC   вместо приглушенного голубого
TEXT_DIM     #888888
CYAN         #00FFFF   максимально яркий
GREEN        #00FF88
AMBER        #FFAA00
RED          #FF0000
```

В HC-режиме все тонкие градиенты и полупрозрачные оверлеи заменяются на solid-цвета, анимации остаются.

---

### 1.3 Правила использования цвета

| Состояние | Акцент | Прогресс-бар | Статус |
|---|---|---|---|
| IDLE | GREEN | GREEN dim | зеленый |
| MOVING | CYAN | CYAN (анимирован) | мигающие стрелки |
| HOMING | AMBER | AMBER пульс | spinner |
| ERROR | RED | RED flash | !!! |
| SLEEP | TEXT_DIM | — | луна |
| PARKING | AMBER→GREEN | — | |

---

## 2. Типографика

**Рекомендуемые шрифты** (конвертируются в GFX bitmap через fontconvert или LovyanGFX font tools):

| Уровень | Шрифт | Размер | Применение |
|---|---|---|---|
| XL | Roboto Mono Bold | 28–32px | Позиция (главный экран) |
| L | Roboto Mono Regular | 18–20px | Скорость, значения в редакторе |
| M | Roboto Condensed | 13–14px | Пункты меню, подписи |
| S | Roboto / system | 8px | Статусбар, подсказки кнопок |

**Важно:** моноширинный шрифт для чисел — цифры не скачут при изменении значения.

Единицы измерения (`steps`, `mA`, `%`) — TEXT_SEC, размер на 2–4px меньше цифры.

---

## 3. Компонентная библиотека

### Статусбар (верхняя строка, 14px)

```
┌────────────────────────────────────────┐
│ [BT●]  CAMERA SLIDER        [▊▊▊░] 11.2V │
└────────────────────────────────────────┘
```

- BT: иконка + цвет: CYAN (подключен) / TEXT_DIM (нет)
- Батарейка: 4 сегмента, цвет: GREEN→AMBER→RED по уровню
- Разделитель снизу: линия DIVIDER 1px

---

### Прогресс-бар позиции

```
  E1◄  ████████████████░░░░░░░░░░  ►E2
       ^              ^
    начало         текущая позиция (белый tick)
```

- Высота: 10px, скруглённые края 2px
- Фон: BG_CARD
- Заполнение: CYAN (движение) / GREEN (стоп)
- Маркер позиции: белая вертикальная линия 2px
- Маркер цели (GoTo): пунктир PURPLE
- Анимация: lerp `displayed += (actual - displayed) * 0.25` каждый кадр (≈50ms)
- Индикаторы эндстопов по краям: "E1◄" / "►E2", цвет RED если активен

---

### Индикатор направления (движущиеся стрелки)

Три стрелки в ряд, поочерёдно зажигаются в направлении движения:

```
BWD:  ◄◄◄  (анимация: ← ← ←)
FWD:  ►►►  (анимация: → → →)
```

- Период смены: 200ms
- Яркость: ярче → тусклее → тусклее (как "бегущий огонь")

---

### Пункт меню

```
┌─────────────────────────────────┐
│  [icon]  Label text    value  ▶ │   ← обычный
├─────────────────────────────────┤
│  [icon]  Label text    value  ▶ │   ← выбранный (BG_HIGHLIGHT + CYAN border left 2px)
└─────────────────────────────────┘
```

- Высота строки: 18px
- Иконка: 12×12, TEXT_SEC в обычном / CYAN в выбранном
- Стрелка ▶: только если есть подменю
- Скроллбар справа (2px, BG_HIGHLIGHT) если пунктов больше 6

---

### Редактор значения

```
┌─────────────────────────────────┐
│ ⚡ Motor Current                │
├─────────────────────────────────┤
│                                 │
│           800                   │   ← 28px, WHITE
│            mA                   │   ← 12px, TEXT_SEC
│                                 │
│  200 ───────────────── 1500     │   ← диапазон
│       ████████████░░░░░░        │   ← слайдер 8px
│                                 │
├─────────────────────────────────┤
│  [✕ CANCEL]          [✓ OK]   │
└─────────────────────────────────┘
```

- При изменении цифра коротко вспыхивает CYAN (50ms)
- Слайдер: фон DIVIDER, заполнение CYAN

---

### Подсказки кнопок (нижняя панель, 16px)

```
╔═══════╗              ╔═══════╗
║ ✕ BCK ║              ║ ✓ OK  ║
╚═══════╝              ╚═══════╝
```

- Скруглённые прямоугольники, 3px radius
- CANCEL: BG_CARD + TEXT_SEC
- OK/GO: BG_CARD + CYAN border
- STOP: RED fill + WHITE text
- HOME: AMBER

---

### Спиннер (хоминг, загрузка)

8-сегментный "часовой" спиннер 16×16 или 24×24:

```
  ╲ | ╱
  ─   ─     (один сегмент светлый, остальные тускнеют)
  ╱ | ╲
```

- Период полного оборота: 600ms
- Цвет: AMBER (хоминг), CYAN (GoTo)

---

## 4. Экраны

### Главный экран (Operational)

```
┌─────────────────────────────────────────┐
│ [BT●]  Camera Slider        [▊▊▊░] 11.2V │  ← статусбар 12px
├─────────────────────────────────────────┤
│                                         │
│  E1◄  ████████████░░░░░░░░░░░  ►E2     │  ← позиция 10px
│                                         │
│         +1 234 steps                    │  ← 28px, WHITE, моно
│         / 5 670 total                   │  ← 12px, TEXT_SEC
│                                         │
│   75%  ══════════════╸   ►► MOVING     │  ← скорость + статус
│                                         │
├─────────────────────────────────────────┤
│  [☰ MENU]    [■ STOP]    [⌂ HOME]     │  ← подсказки кнопок
└─────────────────────────────────────────┘
```

Цвет статуса справа меняется по состоянию (GREEN/CYAN/AMBER/RED).

---

### Экран движения (упрощённый "race mode")

При активном движении к позиции — крупный режим:

```
┌─────────────────────────────────────────┐
│  ►► MOVING TO POSITION          [BT●]  │
├─────────────────────────────────────────┤
│ ██████████████████████░░░░░░░░░░░░░░░  │  ← жирный бар 16px
│                                         │
│           +1 234                        │  ← 32px
│           steps                         │  ← 11px TEXT_SEC
│                                         │
│   75%  ══════════════╸                  │  ← скорость
│                                         │
├─────────────────────────────────────────┤
│               [■ STOP]                  │
└─────────────────────────────────────────┘
```

---

### Экран главного меню (плиточный режим, 4 пункта)

Главное меню — плитки 2×2, иконки 32×32, 4 пункта видно сразу. Если пунктов больше — скролл страницами (следующие 4), индикатор прогресса сверху.

```
┌─────────────────────────────────────────┐
│ ⚙ SETTINGS          ●●●○○○  стр. 1/2  │  ← шапка с dots
├───────────────────────┬─────────────────┤
│                       │                 │
│      [ic32_speed]     │  [ic32_current] │
│                       │                 │
│        Speed          │   Current       │  ← подпись 11px
│         75%           │    800 mA       │  ← значение 13px CYAN
│                       │                 │
├───────────────────────┼─────────────────┤
│                       │                 │
│    [ic32_microstep]   │  [ic32_home]   │  ← выбранная плитка:
│                       │                 │    BG_HIGHLIGHT + CYAN border
│      Microsteps       │    Homing       │
│         32            │      ─          │
│                       │                 │
└───────────────────────┴─────────────────┘
```

- Выбранная плитка: фон BG_HIGHLIGHT, рамка CYAN 2px, иконка перекрашивается в CYAN
- Навигация: энкодер = вправо/влево по плиткам, BTN1 = назад, энкодер-кнопка = enter
- Переход страниц: slide-анимация влево/вправо 120ms

**Страница 2:**

```
│  [ic32_ramp]   │  [ic32_sleep]  │
│    Ramp         │    Sleep       │
│    200 st       │    5 min       │
├────────────────┼────────────────┤
│  [ic32_endstop]│  [ic32_display]│
│  Endstop mode  │   Display      │
│    STOP         │   Default      │
```

---

### Экран подменю (вертикальный список с 16×16 иконками)

Для пунктов внутри раздела — компактный список, 5–6 строк, каждая 18px.

```
┌─────────────────────────────────────────┐
│ ← Display Settings                     │  ← шапка с back
├───────────────────────────────────────┬─┤
│▌  [16×16]  Theme            Default  │█│  ← выбран: BG_HIGHLIGHT
│   [16×16]  High Contrast      OFF    │█│     + CYAN border left 2px
│   [16×16]  Brightness         70%    │ │
│   [16×16]  Sleep Timeout      5 min  │ │
│   [16×16]  Wake on Motion     ON     │ │
└───────────────────────────────────────┴─┘
```

- Скроллбар: правые 3px, CYAN, анимируется вместе с выделением
- Текущий пункт меню всегда остаётся в верхней половине при прокрутке

---

### Экран хоминга/калибровки

```
┌─────────────────────────────────────────┐
│ ⌂ HOMING                               │
├─────────────────────────────────────────┤
│                                         │
│        ◎  Seeking END 1...             │  ← спиннер + фаза
│                                         │
│  Phase  ●●○○○○  2 / 6                  │  ← точки прогресса
│                                         │
│  ←←←←←←←←←←←←←←←                   │  ← анимированные стрелки
│                                         │
│  Travel:  --- steps                     │  ← появляется после END 2
│                                         │
├─────────────────────────────────────────┤
│               [✕ ABORT]                │
└─────────────────────────────────────────┘
```

---

### Экран ошибки

```
┌─────────────────────────────────────────┐
│             ⚠ ERROR                     │  ← RED, мигает 1Hz
├─────────────────────────────────────────┤
│                                         │
│         BLE CONNECTION LOST             │  ← 14px WHITE
│                                         │
│    Motor stopped for safety.            │  ← 11px TEXT_SEC
│                                         │
│                                         │
├─────────────────────────────────────────┤
│  [↺ RESET]              [⌂ HOME]       │
└─────────────────────────────────────────┘
```

Фон пульсирует: BG_BASE ↔ #1A0810 (тёмно-красный), период 800ms.

---

### Экран сна (Wake Screen)

```
┌─────────────────────────────────────────┐
│                                         │
│                                         │
│          ☽  SLEEPING                   │  ← DIM цвета
│                                         │
│       Turn encoder to wake              │  ← TEXT_DIM мелко
│                                         │
│                                         │
└─────────────────────────────────────────┘
```

Луна мигает медленно (1.5s период, яркость 40%↔100%). Wake: fade-in 200ms через brightness или sprite alpha.

---

## 5. Набор иконок

### Размеры и формат

Иконки существуют в **двух размерах** с разным подходом:

| Контекст | Размер | Формат | Цвета |
|---|---|---|---|
| Статусбар | 12×12 | 2-bit indexed (4 цвета) | фон прозрачный + 1–2 цвета |
| Главное меню (крупные плитки) | 32×32 | 4-bit indexed (16 цветов) | 2–3 цвета + фон |
| Подменю / список | 16×16 | 2-bit indexed | 2 цвета + фон |
| Кнопки-подсказки | 10×10 | 1-bit | монохром |

**Формат хранения:** массивы `uint8_t` в flash (PROGMEM). Для 32×32 с 4-bit: 512 байт на иконку — вполне приемлемо. Цвета задаются палитрой из 2–3 RGB565-значений + прозрачность через colorkey.

---

### Главное меню — крупные плитки (32×32)

Главное меню отображает **3–4 пункта** на экране в виде плиток с большой иконкой и подписью. Иконки здесь — полноценные маленькие пиктограммы с 2–3 цветами.

```
┌─────────────────────────────────────────┐
│ ⚙ SETTINGS                    [●●●○○] │  ← шапка + dots-прогресс
├──────────────┬──────────────────────────┤
│              │                          │
│   [32×32]    │   [32×32]               │
│   Speed      │   Current               │
│    75%       │    800mA                │
│              │                          │
├──────────────┼──────────────────────────┤
│              │                          │
│   [32×32]    │   [32×32]               │
│  Microsteps  │   Homing                │
│     32       │    ─                    │
│              │                          │
└──────────────┴──────────────────────────┘
```

Или вертикальный список с крупными иконками (16×16) и прогресс-баром прокрутки:

```
┌─────────────────────────────────────────┐
│ ⚙ SETTINGS                             │
├───────────────────────────────────────┬─┤
│▌  [16×16]  Speed              75 %   │█│  ← выбран
│   [16×16]  Current           800 mA  │█│
│   [16×16]  Microsteps          32    │ │
│   [16×16]  Homing             ▶      │ │
├───────────────────────────────────────┴─┤
│ ▲/▼                         [✓] select │
└─────────────────────────────────────────┘
```

**Прогресс прокрутки** — правый край экрана, 3px полоса:
- Общая высота = область списка
- Заполнение = `(currentIndex / totalItems) * height`
- Цвет: CYAN
- Анимация: lerp за 80ms вместе с выделением

---

### Описание иконок

#### Статусбар (12×12, 2 цвета)

| Иконка | Описание | Цвета |
|---|---|---|
| `ic_bt_on` | Bluetooth — классический символ | CYAN |
| `ic_bt_off` | Bluetooth перечёркнутый | TEXT_DIM |
| `ic_bat_0` | Батарейка пустая | RED |
| `ic_bat_1..4` | Батарейка 25/50/75/100% | AMBER / GREEN |

#### Главное меню (32×32, 2–3 цвета)

| Иконка | Описание | Основной цвет | Акцент |
|---|---|---|---|
| `ic32_speed` | Спидометр: корпус + стрелка + шкала | TEXT_SEC | CYAN (стрелка) |
| `ic32_current` | Молния в круге | AMBER | WHITE (молния) |
| `ic32_microstep` | Сетка точек 4×4 со скобками | TEXT_SEC | CYAN |
| `ic32_ramp` | Трапеция разгона-торможения | CYAN | — |
| `ic32_home` | Домик: крыша + стены + дверь | GREEN | WHITE (дверь) |
| `ic32_sleep` | Луна-серп + три звёздочки | PURPLE | WHITE (звёзды) |
| `ic32_endstop` | Рельс с двумя упорами по краям | TEXT_SEC | RED (упоры) |
| `ic32_adxl` | Куб в изометрии с осями X/Y/Z | TEXT_SEC | CYAN (оси) |
| `ic32_settings` | Шестерня | TEXT_SEC | WHITE (центр) |
| `ic32_ble` | Антенна + волны сигнала | CYAN | — |
| `ic32_calib` | Линейка с делениями + маркер | TEXT_SEC | AMBER (маркер) |
| `ic32_goto` | Дорожка-пунктир + флажок | CYAN | WHITE (флажок) |
| `ic32_display` | Прямоугольник-экран + солнце | TEXT_SEC | AMBER (солнце) |

#### Подменю / список (16×16, 2 цвета)

Упрощённые версии тех же иконок. Детализация меньше, но силуэт узнаваемый.

#### Кнопки-подсказки (10×10, монохром)

| Иконка | Описание |
|---|---|
| `ic10_fwd` | ► |
| `ic10_bwd` | ◄ |
| `ic10_stop` | ■ |
| `ic10_ok` | ✓ |
| `ic10_cancel` | ✕ |
| `ic10_back` | ↩ |
| `ic10_menu` | ☰ |
| `ic10_home` | ⌂ |
| `ic10_reset` | ↺ |
| `ic10_error` | ! |

---

## 6. Анимации

| Анимация | Триггер | Длительность | Описание |
|---|---|---|---|
| Screen slide | переход вперёд/назад в меню | 100ms | экран едет от правого/левого края |
| Menu scroll | поворот энкодера | 80ms | выделение lerp к новой позиции |
| Position bar lerp | каждые 50ms | continuous | `disp += (real - disp) * 0.25` |
| Moving arrows | MOVING состояние | loop 200ms | 3 стрелки "бегут" в направлении |
| Spinner | HOMING / loading | loop 600ms | 8 сегментов, один яркий |
| Value flash | изменение значения | 50ms | цифра вспыхивает CYAN |
| Error pulse | ERROR | loop 800ms | фон пульсирует красным |
| Sleep breathe | SLEEP | loop 3s | луна 40%↔100% brightness |
| Wake fade-in | выход из SLEEP | 200ms | яркость 0→100% (PWM backlight) |
| BT pulse | подключение | loop 1s | иконка пульсирует |

---

## 7. Раскладка дополнительных кнопок

К энкодеру добавляем 2 кнопки. Предлагаемая логика:

```
[BTN1]  [ENCODER BTN]  [BTN2]
  ↑           ↑            ↑
Quick       Select/      Menu/
Action      Confirm      Home
```

**BTN1 — Quick Action (контекстная):**
- Main screen: старт/стоп движения (аналог BLE F/B/S)
- В меню: выйти / назад (снимает нагрузку с энкодера)
- В редакторе: отмена

**BTN2 — Menu / Home:**
- Короткое нажатие: войти в меню / вернуться на главный экран
- Длинное нажатие (800ms): запуск хоминга (с подтверждением на экране)
- В ERROR: сброс ошибки

**Энкодер (кнопка):**
- В меню: select / confirm
- В редакторе: подтвердить значение
- На главном: войти в быстрый GoTo (ввод позиции энкодером)

Это убирает "длинное нажатие" энкодера как навигацию назад — интуитивнее и надёжнее.

---

## 8. Технические рекомендации

### Реализация: Adafruit GFX + полный canvas

```cpp
Adafruit_ST7735 panel(TFT_CS, TFT_DC, TFT_RST);
GFXcanvas16 canvas(160, 128);  // 40 KB обычного heap
// ... рисуем всё в canvas ...
panel.startWrite();
panel.setAddrWindow(0, 0, 160, 128);
panel.writePixels(canvas.getBuffer(), 160 * 128);
panel.endWrite();
```

Физическая панель видит только готовый кадр, поэтому промежуточные очистки и перерисовки не
мерцают. На используемом ESP32-WROOM-32 один такой буфер помещается без PSRAM.

### Память

| Ресурс | Размер |
|---|---|
| Полный экранный буфер (RGB565) | 40 KB |
| Второй буфер (double-buffer) | 40 KB |
| Иконки 32×32 × 4-bit (13 шт меню) | ~7 KB |
| Иконки 16×16 × 2-bit (13 шт подменю) | ~1 KB |
| Иконки 12×12 статусбар (8 шт) | <1 KB |
| Иконки 10×10 монохромные кнопки (10 шт) | <1 KB |
| Шрифт 28px моно (цифры 0–9, +, -, /) | ~3 KB |
| Шрифт 14px sans | ~4 KB |
| Шрифт 8px | ~1 KB |
| **Итого (без PSRAM)** | **~50 KB heap** |
| **С PSRAM** | без ограничений |

### Рекомендация по памяти

- На текущем ESP32-WROOM-32 используется один полный 40-КБ буфер.
- Второй полный буфер не нужен: одна атомарная SPI-отправка уже устраняет видимое мерцание.
- Если появится тяжёлый sprite-атлас или анимации, тогда имеет смысл переходить на ESP32-S3
  с PSRAM, не раньше.

---

## 9. Следующие шаги

1. **Генерация иконок** — три серии: 32×32 (меню, 2–3 цвета, пиксель-арт), 16×16 (подменю, упрощённые), 12×12 (статусбар, 2 цвета). Стиль: чёткий пиксель-арт, технический, без скруглений
2. **Конвертация шрифтов** — взять Roboto Mono (Google Fonts, бесплатный), конвертировать через `fontconvert` в GFX bitmap формат для нужных размеров
3. **Прототип главного экрана** — реализовать статусбар + позиция-бар + state label, убедиться в скорости рендера
4. **Рефакторинг** `slider_10_display.ino` — переписать под LovyanGFX + Sprite с этими компонентами

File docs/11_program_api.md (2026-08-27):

# Program API и рекомендации для пульта

## Зачем нужен отдельный Program API

Обычный сценарий управления должен оперировать готовой программой слайдера, а не
направлением мотора. Слайдер сам отвечает за траекторию, смену направления, концевики и
переходы state machine. Пульт:

1. выбирает программу;
2. показывает и меняет только её публичные параметры;
3. отправляет `START` / `STOP`;
4. отображает подтверждённое состояние из notify.

По умолчанию выбрана программа **Ping-Pong**. Низкоуровневые команды ручного движения,
абсолютной позиции и тока не удаляются, но относятся к отдельному Advanced API.

Такое разделение важно: `Forward` не означает «начать Ping-Pong». Это ручной jog, у
которого другой жизненный цикл и другие ожидания пользователя.

## BLE characteristic

Service UUID остаётся прежним:

`4fafc201-1fb5-459e-8fcc-c5c9c331914b`

Program characteristic (READ / WRITE / NOTIFY):

`c0f1c001-0000-4000-8000-00000000c0de`

### Request v1

Пульт пишет пакет из 6 байт:

| Offset | Поле | Значение |
|---:|---|---|
| 0 | `version` | `1` |
| 1 | `programId` | `0=Manual/Advanced`, `1=Ping-Pong` |
| 2 | `action` | `0=SELECT`, `1=START`, `2=STOP`, `3=CONFIGURE` |
| 3 | `speedPercent` | `1..100`, `0` — не менять |
| 4 | `startPoint` | `0=Center`, `1=Endstop 1`, `2=Endstop 2`, `0xFF` — не менять |
| 5 | `flags` | bit 0 — сохранить параметры в NVS; остальные зарезервированы |

Поля после обязательного заголовка в следующих версиях можно только добавлять в конец.
Неизвестную версию или некорректный диапазон слайдер игнорирует.

`SELECT` не запускает движение и не обязан менять параметры. `CONFIGURE` применяет
параметры к выбранной программе; скорость можно менять во время Ping-Pong. `START`
запускает выбранную программу только когда её prerequisites выполнены. `STOP` имеет
семантику безопасной остановки выбранной программы.

Флаг сохранения не следует ставить при каждом повороте энкодера: live-настройку лучше
держать в RAM, а записывать в NVS отдельным подтверждением пользователя.

### Status v1

Слайдер отправляет notify из 8 байт:

| Offset | Поле | Значение |
|---:|---|---|
| 0 | `version` | `1` |
| 1 | `selectedProgram` | текущий `programId` |
| 2 | `runState` | `0=stopped`, `1=running` |
| 3 | `speedPercent` | фактически применённая скорость `1..100` |
| 4 | `startPoint` | фактически применённая точка старта |
| 5 | `capabilities` | bit 0 — Ping-Pong поддержан; bit 1 — калибровка готова |
| 6 | `sliderState` | общий state слайдера |
| 7 | `errorCode` | общий код ошибки |

Notify является источником истины. Пульт не должен считать программу запущенной только
потому, что BLE write завершился успешно.

## Готовые пакеты Ping-Pong

Выбрать Ping-Pong, не меняя его сохранённые настройки:

```text
01 01 00 00 FF 00
```

Установить скорость 50%, не меняя точку старта и не писать NVS:

```text
01 01 03 32 FF 00
```

Установить скорость 50%, старт из центра и сохранить:

```text
01 01 03 32 00 01
```

Запустить / остановить:

```text
01 01 01 00 FF 00
01 01 02 00 FF 00
```

## Безопасность и состояния

- Ping-Pong требует выполненной калибровки (`capabilities & 0x02`).
- Концевики, реверс и ограничение движения принадлежат прошивке слайдера.
- Любой источник движения проходит низкоуровневую защиту: мотор не запускается в сторону
  уже нажатого концевика.
- Потеря BLE во время движения остаётся аварийным событием и останавливает мотор.
- Повторные `SELECT`, `CONFIGURE`, `START` и `STOP` должны восприниматься пультом как
  идемпотентные намерения; результат всегда уточняется по notify.
- При `sliderState=ERROR` пульт показывает ошибку и не предлагает `START`, пока ошибка не
  сброшена или не выполнено разрешённое восстановление.

## Advanced API

Существующие characteristics сохраняются для диагностики, ручной настройки и
совместимости:

- Command `F/B/S/H/G/Z/R` — ручное движение, homing и сервисные команды;
- Speed — legacy-интервал `100..5000` мкс/шаг;
- Position — абсолютная позиция;
- Current — ток драйвера;
- Status — подробная телеметрия мотора и state machine.

Advanced API нельзя использовать для имитации готовой программы. В частности, пульт не
должен самостоятельно реализовывать Ping-Pong последовательностью `F/B`: он потеряет
синхронизацию при задержках BLE, disconnect и срабатывании концевика.

## Рекомендуемый UX пульта

### Основной экран

- Название выбранной программы: `PING-PONG`.
- Подтверждённый статус `IDLE / RUNNING / ERROR` из Program notify.
- Основные параметры программы: скорость и стартовая точка.
- Одна явная кнопка `START / STOP`.
- Индикаторы E1/E2 и калибровки — только как телеметрия, без локальной имитации логики.

При первом подключении пульт отправляет только `SELECT Ping-Pong`, подписывается на notify
и заполняет UI фактическими настройками слайдера. Он не перезаписывает их своими
дефолтами.

### Настройка

- Энкодер скорости отправляет `CONFIGURE` с новым `speedPercent` и `flags=0`.
- Выбор `Center / Endstop 1 / Endstop 2` меняет `startPoint`.
- Отдельное действие `Save preset` повторяет последний `CONFIGURE` с `flags bit0=1`.
- Во время RUNNING разрешена live-настройка только тех параметров, которые явно
  поддержаны контрактом; сейчас это скорость.

### Advanced

Ручной jog, go-to-position, установка тока, home calibration и reset error должны быть на
отдельном экране `Advanced / Service`. Перед входом в него пульт отправляет Program
`STOP`. Выход из Advanced снова делает `SELECT Ping-Pong`, но не запускает его.

### Совместимость

Если Program characteristic отсутствует, подключён старый firmware:

- пульт помечает режим как `Legacy`;
- может оставить ручные `F/B/S` и legacy Speed;
- не показывает, что Ping-Pong управляется как preset;
- не подменяет Program API локальной автоматизацией.

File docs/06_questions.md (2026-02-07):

# Вопросы по реализации

## Q1: Параметры ramp (разгон/торможение)
В спеке "десятки миллисекунд". Предлагаю дефолт 50мс (при 800мкс/шаг это ~62 шага). Это норм? Диапазон настройки: 20-200мс?

## Q2: Скорость хоминга
В старом коде homingSpeed = 300 мкс/шаг (быстрее обычного 800). Оставляем хардкод или делаем настраиваемой? Быстрее = быстрее калибровка, но жёстче удар по концевику.

## Q3: Порог ADXL345 для детекта движения
Предлагаю: изменение Z > 0.05g относительно baseline за 500мс. Чувствительность настраиваемая (шкала 1-10 в меню, маппится на физические пороги). Ок?

## Q4: Единицы позиции
Сейчас всё в микрошагах. На дисплее и в BLE показывать:
- Сырые микрошаги (просто, точно)
- Проценты хода (требует калибровки)
- Миллиметры (нужен шаг ремня/винта)

Что предпочтительнее? Можно комбинировать (проценты на экране, шаги в BLE)?

## Q5: BLE Status v2 — формат
Предлагаю расширить с 9 до 11 байт:
```
[0-3]  currentPosition (int32 LE)
[4]    флаги (без изменений, обратная совместимость)
[5-8]  travelDistance (int32 LE)
[9]    state enum (uint8: 0=IDLE, 1=MANUAL, 2=MOVE_TO_POS, 3=HOMING, 4=PARKING, 5=ERROR, 6=SLEEP)
[10]   errorCode (uint8: 0=NONE, 1=BLE_LOST, 2=ENDSTOP_FAULT, 3=HOMING_FAIL)
```
Всегда отправлять расширенный формат, без версионирования. Ок?

## Q6: Пункт меню "Programs"
В спеке есть, но без деталей. Варианты:
- Готовые профили движения (постоянная скорость, ease-in-out, timelapse)
- Запись/воспроизведение
- Заглушка "Coming soon"

Что реализуем сейчас?

## Q7: Таймаут сна
Какой дефолт? Предлагаю 5 минут. Диапазон настройки: 1-30 минут с шагом 1 мин.

## Q8: Ускорение энкодера
При прокрутке больших диапазонов (позиция 0-50000) медленно = +1, быстро = x10/x100. Реализуем? Сильно улучшает UX но добавляет сложность.

## Q9: BLE reconnect после ERROR(BLE_LOST)
При переподключении BLE:
- Авто-сброс ошибки (удобнее для юзера)
- Требовать явный Reset Error (по спеке)

Что выбираем?

## Q10: Парковка без калибровки
Если ADXL детектит движение, но калибровки нет (позиция неизвестна):
- Ехать до концевика в любом случае (по направлению от ADXL)
- Отказать в парковке без калибровки

Предлагаю первый вариант — безопасность важнее.

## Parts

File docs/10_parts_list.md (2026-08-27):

# Список компонентов для закупки

Формат: позиция — спецификация — поисковый запрос — количество.

## Контроллер и силовое

| Позиция | Спецификация | Поиск | Кол-во |
|---|---|---|---|
| Плата ESP32 | ESP32-WROOM-32, DevKit V1 / DOIT, **30 пинов**, 4 МБ, CP2102 | `ESP32 DevKit V1 30 pin` | 2 |
| Понижайка DC-DC | вход 9–15 В, выход 5 В / 2 А | `MP1584EN` / `LM2596 step down` | 2 |
| MOSFET N-канальный | логического уровня, TO-220 | `IRLZ44N` | 2 |
| MOSFET P-канальный | TO-220, для верхнего плеча | `IRF4905` | 2 |
| MOSFET N-канальный | 200 В / 9 А, TO-220 | `IRF630` | 2 |
| Модуль soft-latch | коммутация плюса, кнопочное вкл/выкл | `latching power switch module` | 1 |

## Органы управления

| Позиция | Спецификация | Поиск | Кол-во |
|---|---|---|---|
| Концевики | микропереключатель, контакт **NC** | `limit switch microswitch NC` | 4 |
| Выключатель | малогабаритный тумблер | `тумблер MTS-101` | 2 |

## Защита питания

| Позиция | Спецификация | Поиск | Кол-во |
|---|---|---|---|
| Предохранитель | PPTC 2 А, 16 В+ | `PPTC 2A 16V` | 5 |
| Диод Шоттки | 3 А, 40 В | `SS34` / `1N5822` | 5 |
| TVS-супрессор | 15–16 В | `SMBJ15A` / `P6KE16A` | 5 |

## Пассивные

| Позиция | Номинал | Кол-во |
|---|---|---|
| Резисторы | 10 кОм | 10 |
| Резисторы | 1 кОм | 10 |
| Резисторы | 220 Ом, 470 Ом | по 10 |
| Резисторы | 1.5 кОм, 0.25 Вт | 5 |
| Резисторы | 10–100 кОм | 5 |
| Резисторы | **0.11 Ом** (шунт) | 4 |
| Конденсаторы электролит | 220–470 мкФ, 25 В, low-ESR | 4 |
| Конденсаторы керамика | 100 нФ | 20 |

## Разъёмы и монтаж

| Позиция | Спецификация | Поиск | Кол-во |
|---|---|---|---|
| Силовой разъём | XT30 или JST-XH 2.54 | `XT30 connector` / `JST XH 2.54` | 5 пар |
| Гнёзда под ESP32 | 2.54 мм, 15 контактов | `2.54 female header 15 pin` | 4 |
| Провод силовой | 20–22 AWG | `провод силиконовый 20 AWG` | — |
| Провод сигнальный | 24–26 AWG | `провод силиконовый 26 AWG` | — |
| Термоусадка | набор диаметров | `термоусадка набор` | 1 |

---

## Что НЕ подойдёт

- ESP32-**S2 / S3 / C3 / C6** — другая распиновка, прошивка не встанет
- ESP32 на **38 пинов** — не совпадёт разводка платы
- ESP32 с флешем **менее 4 МБ**

---

## В наличии, докупать не нужно

INA226, энкодеры EC11, TMC2209, дисплей ST7735, светодиоды, кнопки.

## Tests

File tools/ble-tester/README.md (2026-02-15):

Chrome BLE tester for Camera Slider

How to run
- Serve this folder over HTTP (Web Bluetooth requires https or localhost):
  - python3 -m http.server 8080
  - then open http://localhost:8080/tools/ble-tester/
- Click “Connect” and pick your device (service filter applies).

What it does
- Subscribes to status notifications (position, flags, travel, state, error).
- Sends commands: Forward, Backward, Stop, Home, Reset error.
- Sets speed %, current mA (uint16 LE), GoTo position (int32 LE).

Device filtering
- By default the Connect dialog filters to devices named Camera_Slider and advertising the slider service UUID.
- Uncheck “Filter to Camera_Slider” to see all BLE devices (still requests access to the slider service).

Notes
- Service/characteristic UUIDs are hardcoded to match firmware.
- Chrome/Edge required; works on desktop with BLE adapter.

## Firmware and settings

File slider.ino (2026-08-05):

// Camera Slider Controller — ESP32 + TMC2209 + BLE
// Main sketch file: includes, pins, globals, setup(), loop()

#include <Wire.h>
#include <PCF8574.h>
#include <U8g2lib.h>
#include <TMCStepper.h>
#include <BLEDevice.h>
#include <BLEServer.h>
#include <BLEUtils.h>
#include <BLE2902.h>
#include <Preferences.h>

// ── ESP32 GPIO pins ──
#define EN_PIN    0
#define STEP_PIN  1
#define DIR_PIN   2
#define VBAT_PIN  3        // ADC: motor supply voltage via resistor divider
#define VBAT_DIVIDER 5.09f // calibrated against multimeter
#define VBAT_FULL  12.6f   // 3S LiPo fully charged (4.2V × 3)
#define VBAT_EMPTY  9.0f   // 3S LiPo empty (3.0V × 3)
#define UART_TX   4
#define UART_RX   5

// ── I2C ──
#define SDA_PIN   8
#define SCL_PIN   9

// ── PCF8574 bit assignments ──
#define PCF_LED       1
#define PCF_ENC_CLK   2
#define PCF_ENC_DT    3
#define PCF_ENC_SW    4
#define PCF_LED2      7
#define PCF_ENDSTOP_1 5   // active LOW
#define PCF_ENDSTOP_2 6   // active LOW

// ── OLED ──
#define SCREEN_WIDTH  128
#define SCREEN_HEIGHT 64
#define OLED_RESET    -1

// ── TMC2209 ──
#define R_SENSE     0.11f
#define DRIVER_ADDR 0b00

// ── ADXL345 registers ──
#define REG_DEVID       0x00
#define REG_BW_RATE     0x2C
#define REG_POWER_CTL   0x2D
#define REG_DATA_FORMAT 0x31
#define REG_DATAX0      0x32

// ── BLE UUIDs ──
#define SERVICE_UUID   "4fafc201-1fb5-459e-8fcc-c5c9c331914b"
#define COMMAND_UUID   "beb5483e-36e1-4688-b7f5-ea07361b26a8"
#define STATUS_UUID    "1c95d5e3-d8f7-413a-bf3d-7a2e5d7be87e"
#define SPEED_UUID     "d8de624e-140f-4a22-8594-e2216b84a5f2"
#define POSITION_UUID  "a1b2c3d4-e5f6-4789-a012-3456789abcde"
#define CURRENT_UUID   "f1e2d3c4-b5a6-4978-9012-3456789abcde"
// Read-only config snapshot over BLE
#define CONFIG_UUID    "c0f1g000-0000-0000-0000-00000000c0de"

// ── State machine ──
enum SliderState {
  STATE_IDLE,
  STATE_MANUAL_MOVING,
  STATE_MOVING_TO_POS,
  STATE_HOMING,
  STATE_PARKING,
  STATE_ERROR,
  STATE_SLEEP
};

enum ErrorCode {
  ERR_NONE = 0,
  ERR_BLE_LOST,
  ERR_HOMING_FAIL,
  ERR_ENDSTOP_UNEXPECTED
};

enum HomingPhase {
  HOME_IDLE,
  HOME_SEEK_END1,
  HOME_BACKOFF1,
  HOME_SEEK_END2,
  HOME_BACKOFF2,
  HOME_GO_CENTER,
  HOME_DONE
};

enum EndstopMode {
  ENDSTOP_STOP   = 0,
  ENDSTOP_BOUNCE = 1,
  ENDSTOP_PARK   = 2
};

// ── LED patterns ──
enum LedPattern {
  LED_OFF,
  LED_ON,
  LED_SLOW_BLINK,   // BLE not connected
  LED_FAST_BLINK,   // ERROR
  LED_PULSE          // moving
};

// ── Menu ──
enum MenuScreen {
  SCREEN_MAIN,
  SCREEN_MENU,
  SCREEN_MANUAL_MOVE,
  SCREEN_GO_TO_POS,
  SCREEN_CALIBRATION,
  SCREEN_SETTINGS,
  SCREEN_MOTION_SETTINGS,
  SCREEN_SLEEP_SETTINGS,
  SCREEN_SYSTEM_SETTINGS,
  SCREEN_WIFI_NETWORKS,
  SCREEN_WIFI_CONNECT,
  SCREEN_WIFI_SCAN,
  SCREEN_WIFI_OTA,
  SCREEN_VALUE_EDIT
};

// ── Hardware objects ──
HardwareSerial TMCSerial(1);
TMC2209Stepper driver(&TMCSerial, R_SENSE, DRIVER_ADDR);
PCF8574* pcf = NULL;
U8G2_SSD1306_128X64_NONAME_F_HW_I2C* oled = NULL;
Preferences preferences;

// ── Hardware presence flags ──
bool pcfFound   = false;
bool oledFound  = false;
bool adxlFound  = false;
uint8_t pcfAddr  = 0;
uint8_t adxlAddr = 0;

// ── BLE ──
BLEServer* pServer = NULL;
BLECharacteristic* pCommandChar  = NULL;
BLECharacteristic* pStatusChar   = NULL;
BLECharacteristic* pSpeedChar    = NULL;
BLECharacteristic* pPositionChar = NULL;
BLECharacteristic* pCurrentChar  = NULL;
BLECharacteristic* pConfigChar   = NULL;

volatile bool bleConnected     = false;
volatile bool bleWasConnected  = false;

// ── BLE command flags (set from BLE callback task, read in loop) ──
volatile bool cmdForward       = false;
volatile bool cmdBackward      = false;
volatile bool cmdStop          = false;
volatile bool cmdHome          = false;
volatile bool cmdGoToPos       = false;
volatile int32_t cmdTargetPos  = 0;
volatile bool cmdSpeedChanged  = false;
volatile uint16_t cmdNewSpeed  = 0;
volatile bool cmdCurrentChanged = false;
volatile uint16_t cmdNewCurrent = 0;

// ── Motor (volatile — shared with ISR) ──
volatile int32_t currentPosition = 0;
volatile bool    motorRunning    = false;
volatile bool    motorDirection  = false;  // false=forward(DIR LOW), true=backward(DIR HIGH)
volatile int32_t motorTargetPos  = 0;
volatile bool    motorHasTarget  = false;
volatile uint32_t stepInterval   = 800;    // current interval in µs
volatile uint32_t targetInterval = 800;    // desired interval in µs
volatile uint32_t rampStepsLeft  = 0;
volatile bool    stopRequested   = false;
volatile bool    stopAfterRamp   = false;  // stop when decel ramp completes

hw_timer_t* stepTimer = NULL;

// ── State ──
SliderState  sliderState   = STATE_IDLE;
ErrorCode    errorCode     = ERR_NONE;
HomingPhase  homingPhase   = HOME_IDLE;

// ── Calibration ──
int32_t travelDistance = 0;
int32_t centerPosition = 0;
bool    isCalibrated   = false;

// ── Config (persisted in NVS) ──
struct Config {
  uint16_t speed;         // 1-100% (bigger = faster)
  uint16_t homingSpeed;   // µs/step for homing
  uint16_t motorCurrent;  // mA (200..1500)
  uint8_t  microsteps;    // 1,2,4,8,16,32,64,128,256
  uint8_t  endstopMode;   // 0=STOP, 1=BOUNCE, 2=PARK
  uint16_t rampSteps;     // steps for accel/decel ramp
  uint16_t sleepTimeout;  // minutes, 0=disabled
  uint8_t  adxlSensitivity; // 0=off, 1=low, 2=mid, 3=high
  bool     wakeOnMotion;
  bool     wifiEnabled;   // WiFi AP + Web API/OTA enabled
  int16_t  wifiSel;       // -1=Auto, otherwise index in WIFI_CREDENTIALS
  int32_t  savedHome;     // user-defined home position
  int32_t  savedTravel;
  int32_t  savedCenter;
  bool     savedCalibrated;
};

Config cfg;

// ── PCF8574 I/O ──
uint8_t pcfOutputState = 0xFD;  // all HIGH except LED bit (P1=0 → LED off)
uint8_t pcfInputState  = 0xFF;  // last read

// ── Endstop state ──
bool endstop1 = false;  // true = triggered
bool endstop2 = false;
bool endstop1Rising = false;  // edge flags, cleared each loop
bool endstop2Rising = false;

// ── Encoder state ──
uint8_t encClkPrev = HIGH;
int8_t  encoderDelta = 0;       // accumulated rotation since last read
bool    encoderPressed = false;  // edge: just pressed
bool    encoderLongPress = false;
bool    encSwState = HIGH;
bool    encSwPrev  = HIGH;
unsigned long encPressTime = 0;
bool    encLongFired = false;

// ── Battery voltage ──
float vbatVoltage = 0;
unsigned long lastVbatRead = 0;

// ── ADXL345 ──
float adxlX = 0, adxlY = 0, adxlZ = 0;
int8_t adxlMotionDir = 0;  // -1 or +1, set by adxlCheckDrift()

// ── Display / Menu ──
MenuScreen currentScreen = SCREEN_MANUAL_MOVE;
int8_t menuIndex = 0;
int8_t menuOffset = 0;
bool   displayDirty = true;
unsigned long lastDisplayUpdate = 0;

// Value editor state
const char* editLabel = NULL;
int32_t editValue = 0;
int32_t editMin = 0;
int32_t editMax = 0;
int32_t editStep = 1;
void (*editCallback)(int32_t) = NULL;
MenuScreen editReturnScreen = SCREEN_MAIN;
const char* const* editValueNames = NULL;  // optional text labels for values

// ── Timing ──
unsigned long lastBleNotify   = 0;
unsigned long lastActivityTime = 0;

// ── Backoff ──
#define BACKOFF_STEPS 200

// ── Forward declarations ──
// (Arduino IDE auto-generates prototypes, but listed for clarity)
void configLoad();
void configSave();
void hwInit();
void motorInit();
void motorStart(bool forward, uint32_t intervalUs);
void motorStop();
void motorStartRamp(bool forward, uint32_t intervalUs);
void motorMoveTo(int32_t position, uint32_t intervalUs);
void stateUpdate();
void pcfPoll();
void endstopsPoll();
void encoderPoll();
void homingUpdate();
void homingStart();
void adxlInit();
bool adxlCheckDrift(uint16_t durationMs);
void bleInit();
void bleStatusNotify();
void ledUpdate();
void ledSetPattern(LedPattern pat);
void displayUpdate();
void menuHandleEncoder();
void sleepCheck();
void sleepEnter();
void sleepWake();
// WiFi/Web API/OTA (disabled for now; keep declarations for future use)
void wifiInit();
void wifiStartIfEnabled();
void wifiStop();
void wifiLoop();
const char* wifiGetIpStr();
bool wifiHasCredentials();
// WiFi known networks (for UI)
int wifiKnownCount();
const char* wifiKnownSsid(int idx);
int wifiKnownRssi(int idx);
int wifiSelectedIndex();
void wifiRequestScan();
bool wifiGetIpPopup(char* buf, size_t len);
// Simple connect workflow for API/OTA
void wifiStartApi();
void wifiStartOta();
int wifiConnectState(); // 0=idle,1=scanning,2=connecting
// View-only scan helpers
void wifiScanStart();
int wifiScanState(); // 0=idle,1=scanning,2=done
int wifiScanCount();
const char* wifiScanSsid(int idx);
int wifiScanRssi(int idx);

void setup() {
  Serial.begin(115200);
  delay(200);

  configLoad();
  hwInit();
  motorInit();
  bleInit();
  // wifiInit(); // disabled
  // Do NOT auto-start WiFi on boot; only start from menu toggle

  lastActivityTime = millis();
}

void loop() {
  // 1. PCF8574: single I2C transaction
  pcfPoll();

  // 2. Endstop edge detection
  endstopsPoll();

  // 3. Encoder rotation + button
  encoderPoll();

  // 3b. Sleep wake check
  sleepCheckWake();

  // 4. State machine transitions
  stateUpdate();

  // 5. Homing sub-automaton
  if (sliderState == STATE_HOMING) {
    homingUpdate();
  }

  // 6. Battery voltage (every 5s, only when motor idle)
  if (!motorRunning && millis() - lastVbatRead > 5000) {
    vbatReadPrecise();
    lastVbatRead = millis();
  }

  // 7. BLE status notify (every 100ms)
  if (bleConnected && millis() - lastBleNotify > 100) {
    bleStatusNotify();
    lastBleNotify = millis();
  }

  // 8. LED pattern update
  ledUpdate();

  // 9. Display update (every 50ms if dirty)
  if (displayDirty && millis() - lastDisplayUpdate > 50) {
    displayUpdate();
    lastDisplayUpdate = millis();
    displayDirty = false;
  }

  // 10. Menu input handling
  menuHandleEncoder();

  // 11. Sleep check
  sleepCheck();

  // 12. WiFi server loop
  // wifiLoop(); // disabled
}

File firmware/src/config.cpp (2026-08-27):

// config.cpp — Config struct, NVS load/save.
// Ported from slider_01_config.ino with schema changes: dropped wakeOnMotion (dead in old
// firmware, never wired to a wake trigger) and wifiEnabled/wifiSel (WiFi/OTA out of scope
// for this port); motorCurrent default fixed to 800mA (old default of 500mA contradicted
// both docs/07_ui_kit.md and the hardware-validated bring-up firmware); homingSpeed kept
// persisted as before, now also exposed in the Motion Settings menu (menu.cpp).
//
// bleEnabled/wifiMode/staSsid/staPass/apPass added later for the Wireless Settings menu.
// wifi_env.h's WIFI_CREDENTIALS[] (gitignored, pre-flash-time convenience) is only
// consulted here, once, to seed NVS on the very first boot (cfg.staSsid still empty) --
// after that NVS is the sole source of truth and the menu is how you change networks.
#include <string.h>
#include "config.h"
#include "globals.h"

#if __has_include("wifi_env.h")
#include "wifi_env.h"  // defines WIFI_CREDENTIALS[] / WIFI_CREDENTIALS_COUNT (gitignored)
#else
struct WifiCred { const char* ssid; const char* pass; };
static const WifiCred WIFI_CREDENTIALS[] = {};
static const size_t WIFI_CREDENTIALS_COUNT = 0;
#endif

// Speed level (1-100) -> us/step for the timer. Level 1 = 5000us (slowest), level 100 =
// 100us (fastest).
//
// The map is geometric, not linear. Perceived speed is step *frequency* (1/interval); a
// linear interval ramp (the old `map(level,1,100,5000,100)`) barely moved the frequency
// until the last few percent, then shot up 25x between 96% and 100%. Here every +1%
// multiplies the frequency by a constant ratio (~4%), so the dial feels linear end to end:
//   level 1  -> 5000us (~200 steps/s)
//   level 25 -> ~2000us (~500 steps/s)
//   level 50 -> ~810us  (~1240 steps/s)
//   level 75 -> ~325us  (~3070 steps/s)
//   level 100 -> 100us  (10000 steps/s)
static const float kSpeedSlowUs = 5000.0f;
static const float kSpeedFastUs = 100.0f;

uint32_t speedToInterval(int32_t level) {
  float t = (constrain(level, 1, 100) - 1) / 99.0f;
  return (uint32_t)lroundf(kSpeedSlowUs * powf(kSpeedFastUs / kSpeedSlowUs, t));
}

uint16_t intervalToSpeed(uint32_t intervalUs) {
  float ratio = constrain(intervalUs, 100UL, 5000UL) / kSpeedSlowUs;
  float t = logf(ratio) / logf(kSpeedFastUs / kSpeedSlowUs);
  return (uint16_t)constrain((long)lroundf(1.0f + t * 99.0f), 1L, 100L);
}

static void configDefaults() {
  cfg.speed           = 50;    // 1-100%, 50 = ~2550us/step
  cfg.homingSpeed      = 400;   // us/step
  cfg.motorCurrent    = 800;
  cfg.microsteps      = 32;
  cfg.endstopMode     = ENDSTOP_STOP;
  cfg.rampSteps       = 200;
  cfg.sleepTimeout    = 5;     // minutes
  cfg.adxlSensitivity = 2;     // mid
  cfg.savedHome       = 0;
  cfg.savedTravel     = 0;
  cfg.savedCenter     = 0;
  cfg.savedCalibrated = false;

  cfg.bleEnabled = true;
  cfg.wifiMode   = WIFI_CFG_OFF;
  cfg.staSsid[0] = 0;
  cfg.staPass[0] = 0;
  strncpy(cfg.apPass, "slider1234", sizeof(cfg.apPass) - 1);
  cfg.apPass[sizeof(cfg.apPass) - 1] = 0;

  cfg.theme = THEME_DARK;
  cfg.brightness = 80;  // ~= the old hardcoded DEFAULT_BACKLIGHT (200/255)

  cfg.speakerEnabled = true;

  cfg.pingPongStart = 0;  // Center
}

void configLoad() {
  configDefaults();

  preferences.begin("slider", true);  // read-only

  cfg.speed           = preferences.getUShort("speed", cfg.speed);
  cfg.homingSpeed      = preferences.getUShort("homSpd", cfg.homingSpeed);
  cfg.motorCurrent    = preferences.getUShort("current", cfg.motorCurrent);
  cfg.microsteps      = preferences.getUChar("usteps", cfg.microsteps);
  cfg.endstopMode     = preferences.getUChar("endMode", cfg.endstopMode);
  cfg.rampSteps       = preferences.getUShort("ramp", cfg.rampSteps);
  cfg.sleepTimeout    = preferences.getUShort("sleepTo", cfg.sleepTimeout);
  cfg.adxlSensitivity = preferences.getUChar("adxlSens", cfg.adxlSensitivity);
  cfg.savedHome       = preferences.getLong("homePos", 0);
  cfg.savedTravel     = preferences.getLong("travel", 0);
  cfg.savedCenter     = preferences.getLong("center", 0);
  cfg.savedCalibrated = preferences.getBool("calib", false);

  cfg.bleEnabled = preferences.getBool("bleEn", cfg.bleEnabled);
  cfg.wifiMode   = preferences.getUChar("wifiMode", cfg.wifiMode);
  preferences.getString("staSsid", cfg.staSsid, sizeof(cfg.staSsid));
  preferences.getString("staPass", cfg.staPass, sizeof(cfg.staPass));
  preferences.getString("apPass", cfg.apPass, sizeof(cfg.apPass));
  if (cfg.apPass[0] == 0) strncpy(cfg.apPass, "slider1234", sizeof(cfg.apPass) - 1);
  cfg.theme = preferences.getUChar("theme", cfg.theme);
  cfg.brightness = preferences.getUChar("bright", cfg.brightness);
  cfg.speakerEnabled = preferences.getBool("spkEn", cfg.speakerEnabled);
  cfg.pingPongStart = preferences.getUChar("ppStart", cfg.pingPongStart);
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

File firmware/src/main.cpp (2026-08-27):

// main.cpp — setup()/loop(), sequences every module's init()/update().
// Loop order mirrors old slider.ino's loop() (input poll, sleep-wake check, state update,
// homing update, throttled power read, throttled BLE notify, LED update, display update,
// menu input, sleep-timeout check) adapted for direct-GPIO input (inputPoll() replaces the
// old pcfPoll()+endstopsPoll()+encoderPoll() trio) and INA226 power (powerRead() replaces
// vbatReadPrecise()).
#include "globals.h"
#include "pins.h"
#include "hw_init.h"
#include "motor.h"
#include "config.h"
#include "state.h"
#include "homing.h"
#include "power.h"
#include "input.h"
#include "adxl.h"
#include "ble.h"
#include "led.h"
#include "buzzer.h"
#include "sleep.h"
#include "display.h"
#include "menu.h"
#include "wifi_module.h"

void setup() {
  Serial.begin(115200);
  delay(200);

  configLoad();
  hwInit();
  ledInit();
  buzzerInit();
  motorInit();
  inputInit();
  adxlInit();
  powerInit();
  powerRead();  // get a real busVoltage_V before the first render -- otherwise the battery
                // icon reads the default 0 (empty/red) for up to a minute, until the
                // throttled read in loop() below fires for the first time.
  if (cfg.bleEnabled) bleInit();
  wifiInit();
  displayInit();
  menuInit();
  buzzerBootChime();

  lastActivityTime = millis();
}

void loop() {
  // 1-3. Input: endstops (edge-detected), encoder rotation + button, BTN1/BTN2.
  inputPoll();

  // 3b. Sleep wake check (must run before menuHandleInput() consumes the same press flags).
  sleepCheckWake();

  // 4. State machine transitions (also drains BLE command flags).
  stateUpdate();

  // 5. Homing sub-automaton.
  if (sliderState == STATE_HOMING) {
    homingUpdate();
  }

  // 6. Power reading -- for the on-screen battery/charging indicator, which doesn't need
  // to track voltage tightly. Once a minute, only when motor idle.
  static unsigned long lastPowerRead = 0;
  if (!motorRunning && millis() - lastPowerRead > 60000) {
    powerRead();
    lastPowerRead = millis();
    // The battery/charge icon in the header only redraws on a screen change or a live
    // animation, neither of which "voltage changed in the background" is -- without this,
    // a stale reading (e.g. the empty/red icon before the very first read landed) could
    // sit on screen indefinitely even after busVoltage_V catches up. displayDirty alone
    // isn't enough: drawScreenHeader()/drawStatusBar() only draw when fullRepaint is set.
    displayForceRepaint();
  }

  // 7. BLE status notify (every 100ms).
  if (bleConnected && millis() - lastBleNotify > 100) {
    bleStatusNotify();
    lastBleNotify = millis();
  }

  // 8. LED pattern update.
  ledUpdate();

  // 9. Display update (self-throttled ~100ms internally, incl. position-bar lerp).
  displayUpdate();

  // 10. Menu input handling.
  menuHandleInput();

  // 11. Sleep timeout check.
  sleepCheck();

  // 12. WiFi/OTA (best-effort; no-op if no credentials configured).
  wifiLoop();
}

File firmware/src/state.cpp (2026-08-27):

// state.cpp — state machine, ported from slider_04_state.ino.
// ERR_ENDSTOP_UNEXPECTED (old: PCF8574-bus-down-while-moving safety) has no equivalent
// dispatch here -- there's no I2C-polled expander on this hardware to fail; the enum value
// is kept reserved for BLE Status-byte compatibility only.
#include "state.h"
#include "pins.h"
#include "motor.h"
#include "homing.h"
#include "config.h"
#include "power.h"

static bool directionBlockedByEndstop(bool forward) {
  return forward ? endstop2 : endstop1;
}

static bool motorIsDrivingIntoEndstop() {
  if (!motorRunning) return false;
  bool forward = !motorDirection;
  return directionBlockedByEndstop(forward);
}

static void startManualMove(bool forward) {
  // F/B are set-direction commands.  Repeating the current direction is idempotent;
  // requesting the opposite direction performs a controlled immediate direction change.
  // This makes a remote's left/right controls deterministic instead of silently ignoring
  // the second command while STATE_MANUAL_MOVING is active.
  if (sliderState == STATE_MANUAL_MOVING && motorRunning) {
    if ((!motorDirection) == forward) return;
    motorStopNow();
  }

  if (directionBlockedByEndstop(forward)) {
    sliderState = STATE_IDLE;
    displayDirty = true;
    return;
  }

  sliderState = STATE_MANUAL_MOVING;
  digitalWrite(MOTOR_EN, LOW);
  driver.rms_current(cfg.motorCurrent);
  motorStartRamp(forward, speedToInterval(cfg.speed));
  displayDirty = true;
}

void stateUpdate() {
  processBleCommands();

  // BLE disconnect during movement -> ERROR
  if (bleWasConnected && !bleConnected) {
    bleWasConnected = false;
    if (sliderState == STATE_MANUAL_MOVING ||
        sliderState == STATE_MOVING_TO_POS ||
        sliderState == STATE_HOMING ||
        sliderState == STATE_PING_PONG) {
      motorStopNow();
      sliderState = STATE_ERROR;
      errorCode = ERR_BLE_LOST;
      displayDirty = true;
      return;
    }
  }
  if (bleConnected) bleWasConnected = true;

  // Check the debounced level, not only the one-loop rising-edge flag.  That closes the
  // hole where a command or mode transition could begin after the edge had already been
  // consumed while the carriage was still holding the switch.
  if (motorIsDrivingIntoEndstop()) {
    handleEndstopHit();
  }

  if (sliderState == STATE_MOVING_TO_POS && !motorRunning) {
    sliderState = STATE_IDLE;
    displayDirty = true;
  }

  // Ping-Pong's first leg (heading to cfg.pingPongStart) uses motorMoveTo(), which stops the
  // motor itself once the target step count is reached -- no endstop involved when the start
  // is Center. Once arrived, kick off the actual bounce cycle. (If the start is an endstop
  // instead, handleEndstopHit() below gets there first and this never fires -- motorRunning
  // is already true again by the time we reach this check.)
  if (sliderState == STATE_PING_PONG && pingPongApproaching && !motorRunning) {
    pingPongApproaching = false;
    bool goForward = (cfg.pingPongStart != 2);  // start=End2 -> first leg is backward
    motorStartRamp(goForward, speedToInterval(cfg.speed));
    displayDirty = true;
  }

  if (sliderState == STATE_MANUAL_MOVING && !motorRunning) {
    sliderState = STATE_IDLE;
    displayDirty = true;
  }

  if (sliderState == STATE_PARKING && !motorRunning) {
    digitalWrite(MOTOR_EN, HIGH);  // disable driver
    sliderState = STATE_IDLE;
    displayDirty = true;
  }
}

void processBleCommands() {
  // High-level preset request. Selection/configuration is orthogonal to execution: a
  // remote can tune Ping-Pong while it is stopped or running, then issue START/STOP.
  if (cmdProgramPending) {
    uint8_t program = cmdProgramId;
    uint8_t action = cmdProgramAction;
    uint8_t speed = cmdProgramSpeed;
    uint8_t startPoint = cmdProgramStartPoint;
    uint8_t flags = cmdProgramFlags;
    cmdProgramPending = false;

    selectedProgram = program;
    if (speed >= 1 && speed <= 100) {
      cfg.speed = speed;
      targetInterval = speedToInterval(cfg.speed);
      if (motorRunning) rampStepsLeft = 50;
    }
    if (startPoint <= 2) cfg.pingPongStart = startPoint;
    if (flags & 0x01) configSave();
    if (action == PROGRAM_STOP) cmdStop = true;
    if (action == PROGRAM_START && program == PROGRAM_PING_PONG) cmdPingPongStart = true;
    displayDirty = true;
  }

  // Speed change (always accepted, BLE sends 1-100)
  if (cmdSpeedChanged) {
    cmdSpeedChanged = false;
    cfg.speed = constrain(cmdNewSpeed, 1, 100);
    targetInterval = speedToInterval(cfg.speed);
    if (motorRunning) {
      rampStepsLeft = 50;  // smooth speed change
    }
    displayDirty = true;
  }

  // Current change (always accepted)
  if (cmdCurrentChanged) {
    cmdCurrentChanged = false;
    cfg.motorCurrent = constrain(cmdNewCurrent, 200, 1500);
    driver.rms_current(cfg.motorCurrent);
    displayDirty = true;
  }

  // Stop command -- highest priority
  if (cmdStop) {
    cmdStop = false;
    if (sliderState != STATE_ERROR) {
      if (motorRunning) motorStopNow();
      if (sliderState == STATE_HOMING) {
        homingPhase = HOME_IDLE;
      }
      sliderState = STATE_IDLE;
      displayDirty = true;
    }
    return;
  }

  // Home command
  if (cmdHome) {
    cmdHome = false;
    if (sliderState == STATE_IDLE || sliderState == STATE_ERROR) {
      if (sliderState == STATE_ERROR) {
        errorCode = ERR_NONE;
      }
      homingStart();
      displayDirty = true;
    }
    return;
  }

  // Forward command -- block if endstop2 (forward end) is triggered
  if (cmdForward) {
    cmdForward = false;
    if (sliderState == STATE_IDLE || sliderState == STATE_MANUAL_MOVING) {
      startManualMove(true);
    }
    return;
  }

  // Backward command -- block if endstop1 (backward end) is triggered
  if (cmdBackward) {
    cmdBackward = false;
    if (sliderState == STATE_IDLE || sliderState == STATE_MANUAL_MOVING) {
      startManualMove(false);
    }
    return;
  }

  // Go to position command -- block if moving toward a triggered endstop
  if (cmdGoToPos) {
    cmdGoToPos = false;
    if (sliderState == STATE_IDLE && isCalibrated) {
      int32_t target = constrain(cmdTargetPos, 0, travelDistance);
      bool wouldGoForward = target > currentPosition;
      bool blocked = (wouldGoForward && endstop2) || (!wouldGoForward && endstop1);
      if (!blocked) {
        sliderState = STATE_MOVING_TO_POS;
        digitalWrite(MOTOR_EN, LOW);
        driver.rms_current(cfg.motorCurrent);
        motorMoveTo(target, speedToInterval(cfg.speed));
        displayDirty = true;
      }
    }
    return;
  }
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

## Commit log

2026-02-07 Initial commit: ESP32 camera slider firmware
    12-file modular Arduino sketch with hardware timer ISR motor control,
    non-blocking state machine, BLE, OLED menu, ADXL345 safety, and sleep mode.
2026-02-07 Fix endstop polarity: active HIGH on PCF8574
    [slider_05_endstops.ino]
2026-02-07 Show text labels in value editor for endstop mode, ADXL sensitivity, wake on motion
2026-02-09 Block movement toward already-triggered endstop
    Prevents starting motor in the direction of a pressed endstop
    via BLE commands, encoder manual move, and GoToPosition.
    [slider_04_state.ino, slider_11_menu.ino]
2026-02-14 Change speed from µs/step to intuitive 1-100% scale
    - Add speedToInterval() mapping: level 1 = 5000µs, level 100 = 100µs
    - Default speed 50%, encoder CW = faster
    - All motor start/ramp/moveTo calls use speedToInterval(cfg.speed)
    - Display shows "Speed: XX%" on main and manual move screens
    - Value editor range 1-100 step 5
2026-02-15 Add battery monitoring, LED2 indicator, safe parking before sleep, ADXL rework
    - GPIO3 as VBAT ADC with calibrated divider (1MΩ/220kΩ, ratio 5.09)
    - Precise ADC read (10x averaged, TMC silenced) when motor idle
    - Quick ADC read during endstop bounce
    - Battery % displayed top-right on main screen
    - LED2 (PCF P7): solid >50%, blink 1/min 10-50%, blink 1/10s <10%
    - ADXL reworked: no constant polling, only blocking drift check before sleep
    - Sleep: release motor → check drift 3s → park to endstop if needed → retry
    - Removed dead fallback GPIO endstop code
    [slider.ino, slider_02_hw.ino, slider_04_state.ino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]
2026-02-15 Update CLAUDE.md to reflect current modular firmware architecture
    The old CLAUDE.md described the monolithic old/main_old.ino and referenced
    non-existent slider_functions.ino. Updated to document all 12 active slider_*.ino
    modules, state machine, hardware timer ISR motor control, BLE protocol v2,
    NVS config keys, PCF8574 pin assignments, I2C device autodetection, ADXL345
    drift detection, battery monitoring, OLED menu system, and key conventions.
    https://claude.ai/code/session_01PGN9T7AWtUwzKVZcpwNeeV
2026-02-15 Raise I2C clock to 400kHz to reduce bus saturation
    OLED framebuffer transfer drops from ~93ms to ~23ms per update.
    All three I2C devices (PCF8574A, SSD1306, ADXL345) support 400kHz.
    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
2026-02-15 Throttle PCF8574 polling to every 2ms (500 Hz)
    Was polling every loop iteration (~thousands/sec), saturating the I2C bus.
    500 Hz is more than sufficient for encoder and endstop edge detection.
    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
2026-02-15 Add I2C resilience: timeout, retry, bus re-init, emergency stop
    Cherry-picked from feature/i2c-resilience, adapted to our 400kHz + throttle:
    - Wire.setTimeOut(10ms) prevents bus lockup from hanging loop
    - pcfPoll: 2 attempts with direct Wire calls before giving up
    - Bus re-init (Wire.begin) if PCF unresponsive >200ms
    - Emergency motorStopNow() + ERROR if PCF lost >500ms during movement
    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
    [slider_02_hw.ino, slider_05_endstops.ino]
2026-02-15 Fix PCF8574 I2C re-init spam: init lastPcfOk, rate-limit recovery
    - lastPcfOk was initialized to 0, so first failed poll triggered
    re-init immediately (downMs = time since boot >> 200ms)
    - Re-init had no cooldown — fired every 2ms, flooding serial
    - Fix: initialize lastPcfOk on first call, rate-limit re-init
    to once per 3 seconds, raise thresholds
    - Pass SDA/SCL pins to pcf->begin() to prevent library from
    resetting I2C to default GPIO 21/22
    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
    [slider_02_hw.ino, slider_05_endstops.ino]
2026-02-15 Fix compile: PCF8574 library has no begin(sda, scl) overload
    Revert to pcf->begin() — Wire pins already set by Wire.begin(SDA_PIN, SCL_PIN)
    before PCF8574 init, so no pin reset issue with this library version.
    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
    [slider_02_hw.ino]
2026-02-15 I2C: авто‑перепривязка PCF (0x20/0x21), опрос 5мс + ретраи; убрать отладочные логи. OLED: u8g2, инкрементальные updateDisplay, переход на 50кГц для Wire; сон/пробуждение через setPowerSave. Ток двига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
2026-02-15 I2C: вернуть частоту Wire на 100 кГц (init и re-init).
2026-02-15 WiFi: switch to STA with env-based credentials. Add wifi_env.h.example and ignore wifi_env.h. Remove AP; keep API + OTA routes only. Auto-reconnect logic.
2026-02-15 Chore: remove all Serial debug prints (USB logging) across codebase to reduce size and noise. No functional changes.
    [slider.ino, slider_01_config.ino, slider_02_hw.ino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]
2026-02-15 Disable Wi‑Fi features without deleting code: comment out init/loop calls and hide Wi‑Fi items from Settings. Keep Wi‑Fi sources for later re‑enablement.
2026-02-15 UI: wrap menu index on encoder rotation (cyclic navigation across all menus)
2026-02-15 BLE tester: add 'Go Home (Center)' button (sends goto travel/2)
2026-02-15 Motor: add holding torque after wake (30% of cfg current). Restore run current on motion start (forward/backward/goto/homing). BLE tester: ping-pong offsets + dwell and Go Home (Center).
2026-08-05 BLE: add saved-home commands (G/H go-to, Z save) and read/notify config snapshot characteristic. Sleep: extend ADXL drift-check window to 5s for more reliable parking. BLE tester: UI updates for new 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
    [slider.ino, slider_08_ble.ino, slider_12_sleep.ino]
2026-08-05 TFT UI: add prep materials for graphics migration (ESP32-S3 + ST7735)
    - docs/07_ui_kit.md: full UI kit spec (colors, typography, components, screens, animations)
    - docs/08_icon_prompts.md: AI icon generation prompts
    - hardware/: KiCad schematic project for new controller board
    - tools/generate_icons*.py, icons_comfy/: generated icon set (12/16/32px PNGs)
    - tools/icons_to_h.py: PNG -> RGB565 header converter
    - tools/tft_icon_test/: standalone ST7735 icon-rendering test sketch
    [slider.kicad_sch]
2026-08-05 firmware: add PlatformIO input-test sketch for ESP32-WROOM-32 + ST7735
    Bring-up test for the new TFT hardware revision: rotary encoder (CLK/DT/SW),
    BTN1/BTN2, ENDSTOP_1/2, status LEDs, and one-step-per-tick TMC2209 motor
    control, all shown live on the ST7735 display.
    Found and worked around a real ESP32-hal-spi.c gotcha along the way: passing
    miso=-1 to SPI.begin() does not disable MISO, it falls back to the VSPI
    default (GPIO19) and silently strips any pull-up configured on that pin.
    Since ENC_SW lives on GPIO19, this broke the encoder button until MISO was
    redirected to an actually-unused pin (GPIO12) instead of -1.
    [main.cpp]
2026-08-05 firmware: add INA219 power monitoring and ADXL345 tilt readout
    - ADXL345: register-level driver ported directly from the current
    slider_02_hw.ino / slider_07_adxl.ino (same address probe, DEVID check,
    and full-resolution +-2g config), no extra library needed.
    - INA219 (bus voltage + current) via Adafruit_INA219 on the same I2C bus
    (SDA=21, SCL=22).
    - Both sensors polled every 200ms and rendered as two new status rows.
    - Shrunk the encoder counter to size2 and tightened row spacing to fit the
    two new rows on the 128px-tall display.
    BTN1/BTN2 also remapped to control backlight brightness (dim/bright) per
    request, and status LEDs now mirror ENDSTOP_1/2 instead of the buttons.
    [main.cpp]
2026-08-16 slider-v2: full firmware port to ESP32-WROOM-32 + ST7735 graphical UI
    Reuses the old firmware's control logic (motor ISR/ramp, state machine,
    6-phase homing, BLE protocol, ADXL drift parking, sleep, NVS config)
    adapted to the new hardware, paired with a new graphical UI driven by the
    3-input model (encoder + BTN1 + BTN2).
    Firmware (firmware/src, firmware/include):
    - motor.cpp: timer API translated to the 2.x-style signatures this core
    actually exposes; alarm now disabled on every stop (it previously kept
    firing forever after the first move and corrupted SPI transfers)
    - display.cpp: UI-kit palette as runtime-selectable themes (Dark / Light /
    High Contrast), drawn menu icons instead of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
    [adxl.cpp, ble.cpp, config.cpp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]
2026-08-21 Redesign slider display UI
    [display.cpp]
2026-08-27 firmware: ping-pong mode, high-level program API, buzzer, LED PWM & hw fixes
    Bundles the codex/ui-redesign firmware WIP; the shared files (menu.cpp,
    globals.h, display.cpp, state.cpp) carry several of these threads mixed at
    the hunk level and don't split cleanly.
    - Ping-Pong: new STATE_PING_PONG / SCREEN_PING_PONG, bounces between the
    endstops from a configurable start point (Center/E1/E2), BTN1 start/stop,
    ignores the global Endstop Mode. Motion Settings gains 'PingPong Start'.
    - High-level Program API: new PROGRAM characteristic (select/configure/
    start/stop a preset, 6-byte request + 8-byte status), so remotes drive
    presets instead of streaming F/B. selectedProgram, SliderProgram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
    [adxl.cpp, ble.cpp, buzzer.cpp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]
